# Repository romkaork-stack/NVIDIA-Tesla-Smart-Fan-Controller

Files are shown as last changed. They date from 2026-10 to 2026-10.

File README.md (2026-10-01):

# NVIDIA Tesla Smart Fan Controller 🌬️🤖

An automatic, ultra-lightweight smart fan controller for passive server-grade GPUs (**NVIDIA Tesla A2, P4, T4**, etc.) in desktop PCs, built with a **.NET WinForms (NVML)** engine and an **Arduino Nano** driver.

---

## 📜 The Story Behind the Project (Background)

This project was born out of a very specific hardware challenge. I wanted to build a compact, high-performance AI and media node using a **Lenovo ThinkCentre M920x Tiny** micro-PC and a low-profile, passive enterprise accelerator — the **NVIDIA Tesla A2**. 

<p align="center">
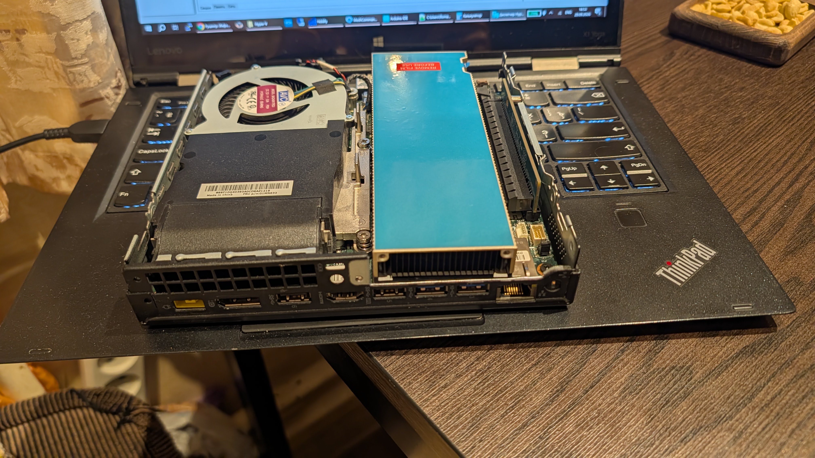
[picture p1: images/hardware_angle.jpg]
NVIDIA Tesla A2 inside Lenovo M920x
  
  <br>
  <i>NVIDIA Tesla A2 passive heatsink aligned with the chassis exhaust</i>
</p>

However, two major roadblocks immediately appeared:
1. **Locked Embedded Controller (EC):** The Lenovo motherboard completely blocks any third-party software control over the system fan bus. Utilities like SpeedFan, FanCtrl, or Notebook FanControl are entirely powerless here.
2. **Passive Server Cooling:** Server GPUs like the Tesla A2 do not have an onboard fan connector or fan controller. They rely purely on the massive airflow of server racks, meaning that inside a desktop or mini-PC, the card would quickly overheat and throttle under any AI or compute load.

To solve this, I designed a **hybrid hardware-software cooling system**. Instead of fighting the locked Lenovo EC, I installed a dedicated external cooling fan onto the Tesla A2 and wired it directly to an **Arduino Nano**. 

The C# Windows application silently monitors the GPU core via the native **NVIDIA Management Library (NVML)**, calculates the required PWM percentage, and streams it to the Arduino. To eliminate any chance of overheating if the software crashes, the Arduino runs a hardware watchdog timer — if it doesn't hear from Windows for 6 seconds, it overrides everything and spins the fan to 100%.

The result is a whisper-quiet mini-PC at idle, and a perfectly cooled, stable enterprise GPU under full load!

### 🌪️ Why Exhaust (Pull) Configuration Instead of Intake (Push)?
A common question in cooling design is why this system is set to pull hot air *away* from the GPU heatsink and exhaust it out of the chassis, rather than blowing cold air directly *onto* it. There are three major engineering reasons for this setup, **backed by real-world thermal testing**:

> ⚠️ **Empirical Proof:** During development, an intake (push) configuration was fully tested using the exact same blower fan. Under a heavy compute/AI load, the results were disastrous — the GPU core temperature rapidly broke through **80°C** and kept climbing due to air stagnation. Switching to the exhaust (pull) layout instantly dropped and stabilized the temps at **60-63°C**.

1. **Server Heatsink Aerodynamics:** The passive radiator on the Tesla A2 is geometrically optimized for straight-through, tunnel-like airflow. High-pressure blower fans (shrouded laptop impellers) work significantly better by creating a low-pressure vacuum inside the shroud, smoothly drawing air *through* the dense fins along their native path, rather than hitting them at a dead-angle and creating turbulent stall zones.
2. **Component-Wide Thermal Relief:** By vacuuming air out through the back, cold ambient air is naturally drawn into the tiny Lenovo chassis through its side ventilations. This airflow travels across the entire surface of the Tesla A2, successfully cooling not just the core chip, but also the VRAM and critical VRM power delivery zones before being ejected.
3. **Preventing the "Oven Effect":** Blowing air *into* the heatsink would trap high-velocity, 65°C+ air inside the incredibly tight spaces of the micro-PC, heating up adjacent system memory, NVMe SSDs, and the motherboard components. The exhaust configuration cleanly isolates the GPU's thermal loop from the rest of the host system.

---

## 📸 Screenshots

<p float="left" align="center">
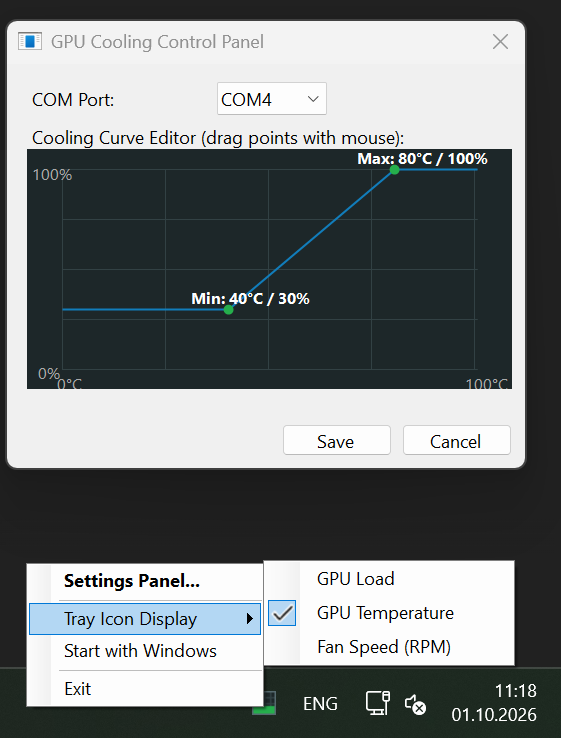
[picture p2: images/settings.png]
Cooling Curve Editor
  
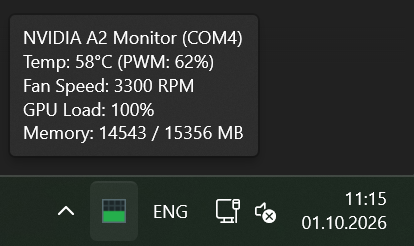
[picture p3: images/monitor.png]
Real-Time Streaming Graph
  
</p>

<p align="center">
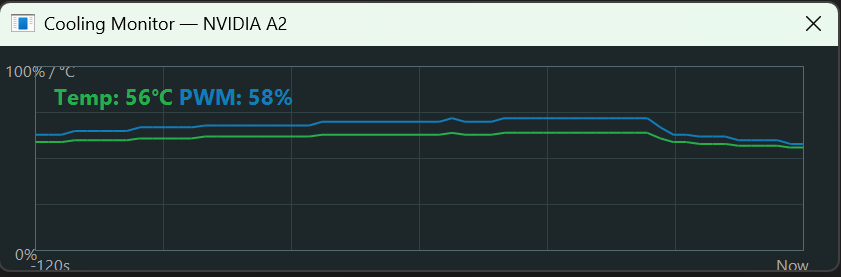
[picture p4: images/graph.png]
Animated Tray Icon Grid
  
  <br>
  <i>Animated Tray Icon Grid</i>
</p>

<p float="left">
  <span style="display: inline-block; width: 48%; text-align: center;"><i>Cooling Curve Editor UI</i></span>
  <span style="display: inline-block; width: 48%; text-align: center;"><i>Real-Time Temperature & PWM Graph</i></span>
</p>

<p float="left" align="center">
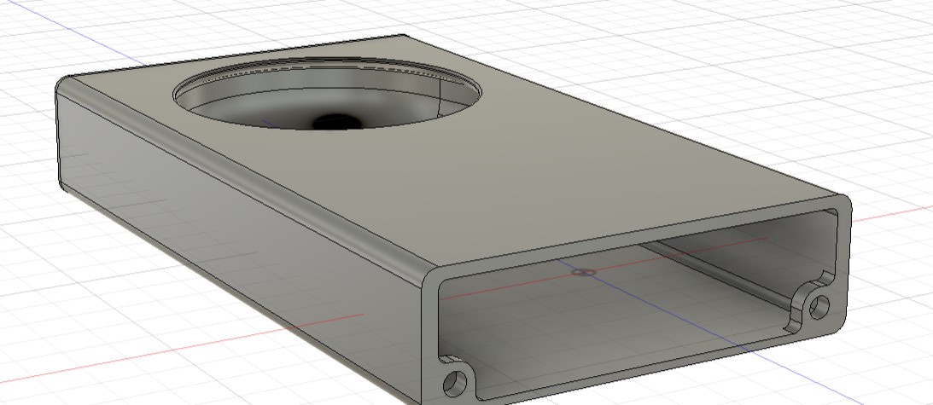
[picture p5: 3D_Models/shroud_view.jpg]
Fan Shroud 3D Model
  
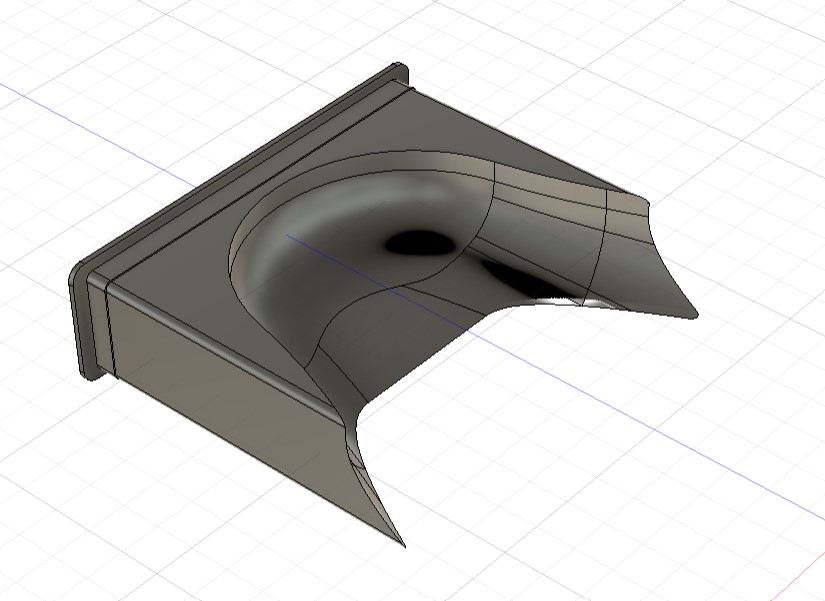
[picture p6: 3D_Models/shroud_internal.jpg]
Internal Airflow Duct Geometry
  
</p>

<p float="left">
  <span style="display: inline-block; width: 48%; text-align: center;"><i>Custom Fan Shroud 3D Model</i></span>
  <span style="display: inline-block; width: 48%; text-align: center;"><i>Internal Airflow Duct Geometry (Autodesk Fusion)</i></span>
</p>

---

## ✨ Features
* **Zero-CPU Overhead Monitoring:** Uses `nvml.dll` to directly query driver memory without heavy shell execution.
* **Hardware Failsafe Protection:** Arduino watchdog spins the fan to 100% if the app closes or freezes for 6 seconds.
* **Silent 25 kHz PWM Signal:** Reconfigured hardware timers eliminate motor buzzing at low speeds.
* **Animated Tray Icon & Monitor:** Real-time tracking and double-click streaming graphs for temperature and PWM.
* **Interactive Cooling Curve UI:** Easily adjust custom cooling targets via the graphical editor.

---

## 🔌 Hardware Specs & Wiring Diagram

The entire cooling system is highly efficient and runs **completely off a single USB port (5V)**, eliminating the need for any external 12V power bricks. 

### Hardware components used:
* **Arduino Nano** (ATmega328P) wrapped in Kapton tape for insulation.
* **5V Laptop Blower Fan** (with PWM support).
* Standard **Mini-USB cable** for simultaneous 5V power supply and serial data transfer from Windows.

### 📐 Wiring Layout:
* **Fan GND** -> **Arduino GND**
* **Fan 5V VCC** -> **Arduino 5V pin**
* **Fan PWM** -> **Arduino Pin D9**
* **Fan Tachometer / Tach** -> **Arduino Pin D2** (*Hardware Interrupt*)

<p align="center">
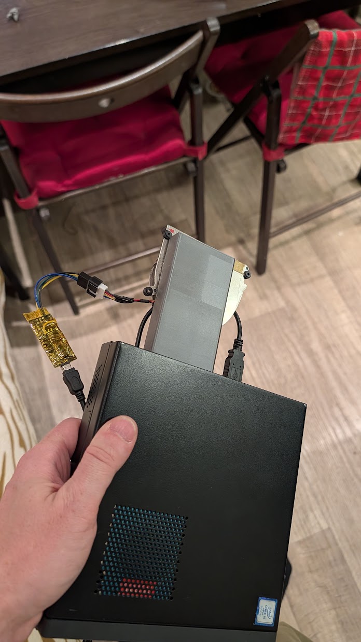
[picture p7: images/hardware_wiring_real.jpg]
Real hardware connections and insulation
  
  <br>
  <i>Real-world hardware setup: Arduino Nano in Kapton tape powered via Mini-USB</i>
</p>

---

## 🚀 Quick Start / Deployment

### 0. 3D Printing
Print the custom fan shroud located in the `/3D_Models` folder using PETG or ABS filament (recommended due to GPU operating temperatures) to securely mount your external fan.

### 1. Flash the Arduino
1. Open the sketch provided in the `/Arduino` directory inside your Arduino IDE.
2. Select your **Arduino Nano** (ATmega328P) board and upload the code.

### 2. Get the Windows App

<p align="left">
  <a href="https://github.com/romkaork-stack/NVIDIA-Tesla-Smart-Fan-Controller/releases/tag/v1.0.0">
    
  </a>
</p>

Download the pre-compiled executable directly using the button above, or compile it from source within the project folder using .NET CLI commands:

<details>
<summary>🛠️ Click to view Manual Compilation Guide</summary>

Navigate to your project directory in terminal and run:
```bash
dotnet add package Microsoft.Win32.Registry
dotnet publish -c Release -r win-x64 --self-contained false -p:PublishSingleFile=true
```
Grab your standalone `TeslaFanController.exe` from the `bin/Release/.../publish/` folder and drop it into your preferred storage directory.
</details>

### 3. Execution & Configuration
1. Run the app (no admin rights needed for core NVML reading).
2. Configure `config.txt` and fine-tune cooling lines via the tray settings panel.
3. Enable **"Start with Windows"** to automate GPU cooling on startup.

---

## 📄 License
This project is licensed under the MIT License - see the [LICENSE](LICENSE) file for details.

---

## 🤝 Credits
This project, including the entire .NET background application, low-level NVML logic, interactive GUI, and custom Arduino firmware, was co-created, designed, and fully written in collaboration with **Google Gemini**.

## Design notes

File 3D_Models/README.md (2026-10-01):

# 3D Printable Models

Here you can find the `.stl` and `.step` files for the custom fan shroud.

<p align="center">
  
  
  <br>
  <i>Custom cooling duct with aerodynamic curvature designed in Autodesk Fusion</i>
</p>

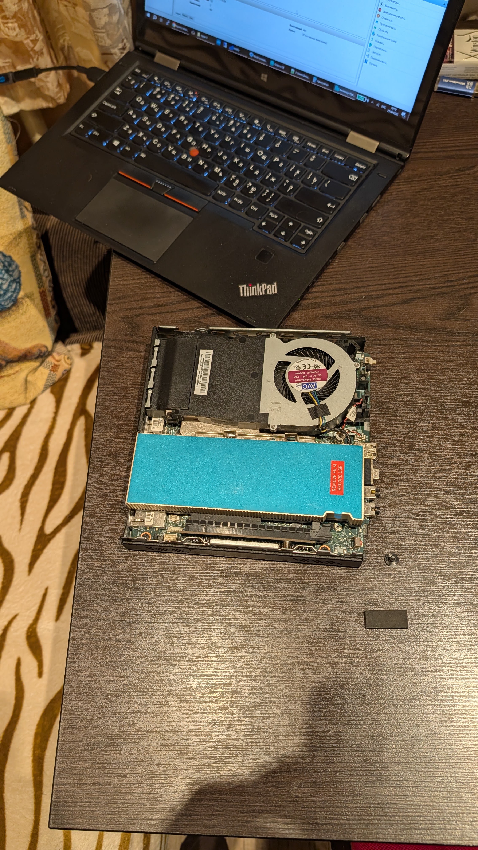
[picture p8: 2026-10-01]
images/hardware_top.jpg

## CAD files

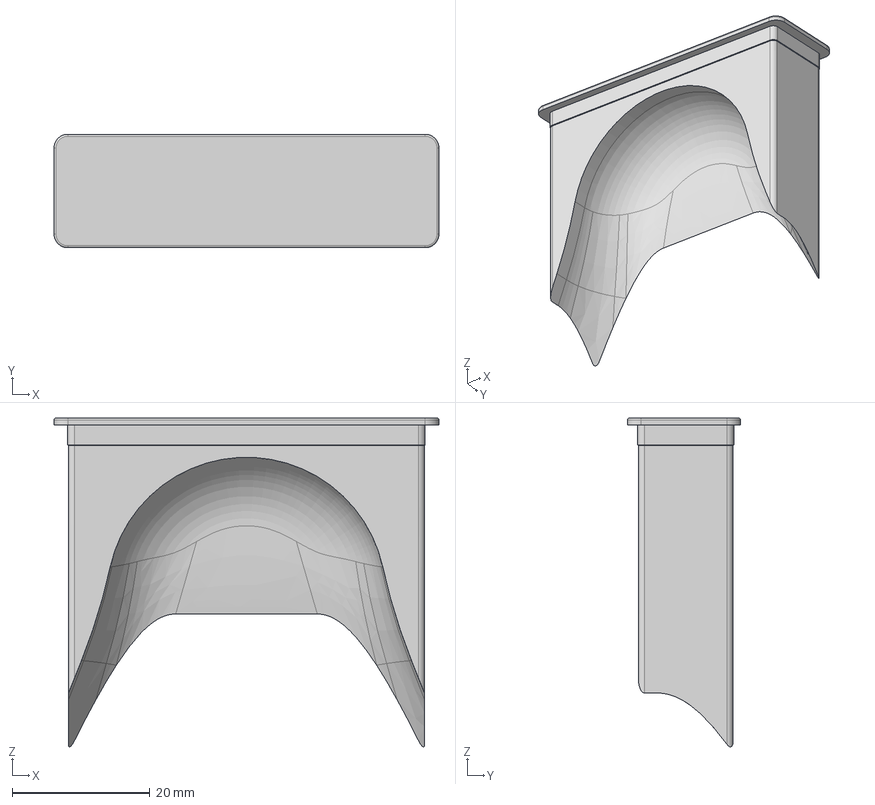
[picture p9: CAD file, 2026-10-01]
3D_Models/Tesla A2 FAN2.step
56.0 x 16.5 x 47.8 mm

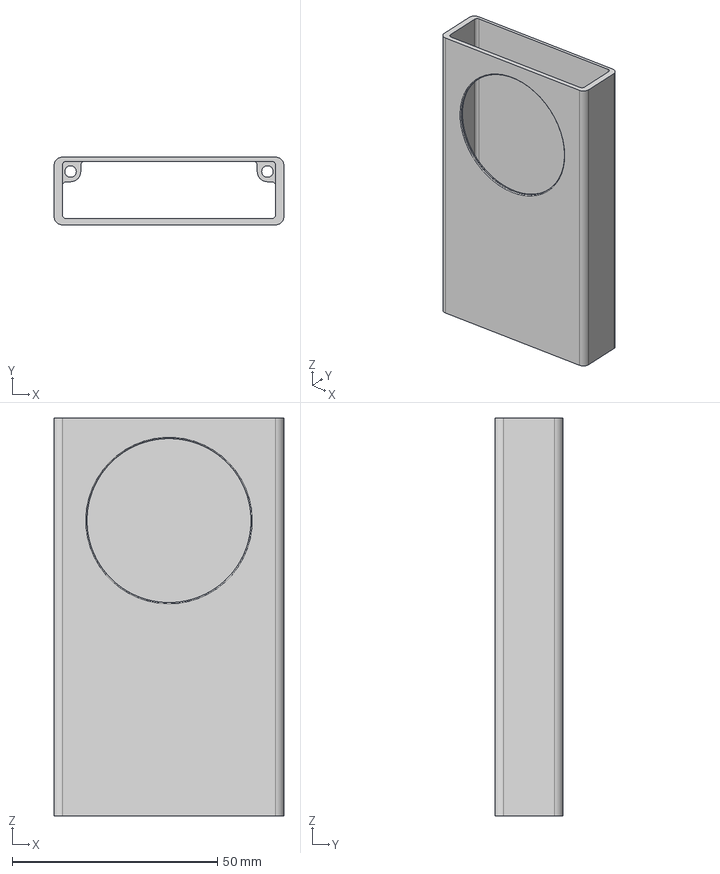
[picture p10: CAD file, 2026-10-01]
3D_Models/Tesla A2 FAN1.step
56.0 x 16.5 x 97.0 mm

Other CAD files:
3D_Models/Tesla A2 FAN1.stl
3D_Models/Tesla A2 FAN2.stl

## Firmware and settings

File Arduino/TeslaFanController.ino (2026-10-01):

// ============================================================================
// Project: NVIDIA Tesla Smart Fan Controller (Arduino Firmware)
// Co-created with: Google Gemini (AI Assistant)
// ============================================================================

// 25 kHz PWM configuration, Failsafe protection, and RPM calculator
volatile unsigned int pulseCount = 0;
unsigned long lastRPMCalc = 0;
unsigned long lastDataReceived = 0;
unsigned int currentRPM = 0;

const unsigned long FAILSAFE_TIMEOUT = 6000; // 6 seconds watchdog timeout

void rpmPulseISR() {
  pulseCount++;
}

void setup() {
  Serial.begin(9600); // Initialize serial communication
  
  pinMode(9, OUTPUT);
  pinMode(2, INPUT_PULLUP); // Tachometer pin with internal pull-up
  attachInterrupt(digitalPinToInterrupt(2), rpmPulseISR, FALLING);
  
  // Configure Timer 1 for true 25 kHz PWM frequency
  TCCR1A = _BV(COM1A1) | _BV(WGM11);
  TCCR1B = _BV(WGM13) | _BV(CS10);
  ICR1 = 320; // Top counter limit: 16MHz / (2 * 25000Hz) = 320
  
  setPWM(100); // Start at 100% speed for safety
  lastDataReceived = millis();
}

void loop() {
  // Watchdog check (Failsafe protection)
  if (millis() - lastDataReceived > FAILSAFE_TIMEOUT) {
    setPWM(100); // Spin fan at maximum speed if PC is not responding
  }

  // Read incoming bytes from the COM port
  if (Serial.available() > 0) {
    String input = Serial.readStringUntil('\n'); 
    int targetPwm = input.toInt(); // The PC sends calculated PWM percentage directly
    
    // Ensure the received value is a valid PWM percentage (0 to 100%)
    if (targetPwm >= 0 && targetPwm <= 100) {
      lastDataReceived = millis(); // Reset safety watchdog timer
      setPWM(targetPwm);           // Apply duty cycle to the fan directly
    }
  }

  // Calculate and transmit Fan RPM to Windows every 1 second
  if (millis() - lastRPMCalc >= 1000) {
    detachInterrupt(digitalPinToInterrupt(2)); // Temporarily disable interrupts for accuracy
    
    // Most standard fans output 2 pulses per single full revolution
    currentRPM = (pulseCount * 60) / 2; 
    pulseCount = 0;
    lastRPMCalc = millis();
    
    attachInterrupt(digitalPinToInterrupt(2), rpmPulseISR, FALLING);
    
    // Send RPM stats back to the PC application
    Serial.print("RPM:");
    Serial.println(currentRPM);
  }
}

// Function to update the PWM Duty Cycle (0 - 100%)
void setPWM(int percent) {
  int dutyCycle = map(percent, 0, 100, 0, 320);
  OCR1A = dutyCycle;
}
